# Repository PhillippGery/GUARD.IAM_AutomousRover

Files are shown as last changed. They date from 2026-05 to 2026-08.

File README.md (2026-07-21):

# GUARD.IAM

<p align="center">
  
  
  
  
  
  
  
</p>

<p align="center">
  <b>🥈 2nd Place — Microsoft Track &nbsp;·&nbsp; 🥉 3rd Place — AMD Track</b><br>
  <i>StarkHacks 2026 · World's Largest Hardware Hackathon · 750+ participants · 36 hours</i>
</p>

**G**round **U**nit for **A**utonomous **R**econnaissance, **D**istal **I**ntervention, and **A**rm **M**anipulation — a fully autonomous confined space intervention rover with dual robotic arms, built from scratch in 36 hours at StarkHacks 2026. GUARD.IAM navigates autonomously to a target, executes bimanual manipulation tasks, and hands off to a human operator via **Meta Quest 3 Mixed Reality** when a decision is too critical to automate.

---

## Table of Contents

- [Demo](#demo)
- [Overview](#overview)
- [System Architecture](#system-architecture)
- [Subsystems](#subsystems)
  - [Autonomous Navigation](#autonomous-navigation)
  - [Mecanum Drive & Motor Control](#mecanum-drive--motor-control)
  - [Sensor Fusion & Localization](#sensor-fusion--localization)
  - [Dual-Arm Manipulation](#dual-arm-manipulation)
  - [Mixed Reality Teleoperation](#mixed-reality-teleoperation)
  - [LeRobot Imitation Learning](#lerobot-imitation-learning)
- [Key Algorithms](#key-algorithms)
- [Project Structure](#project-structure)
- [Installation & Build](#installation--build)
- [Running the System](#running-the-system)
- [Configuration Reference](#configuration-reference)
- [ROS2 Topic Reference](#ros2-topic-reference)
- [Dependencies](#dependencies)
- [Team](#team)

---

## Demo

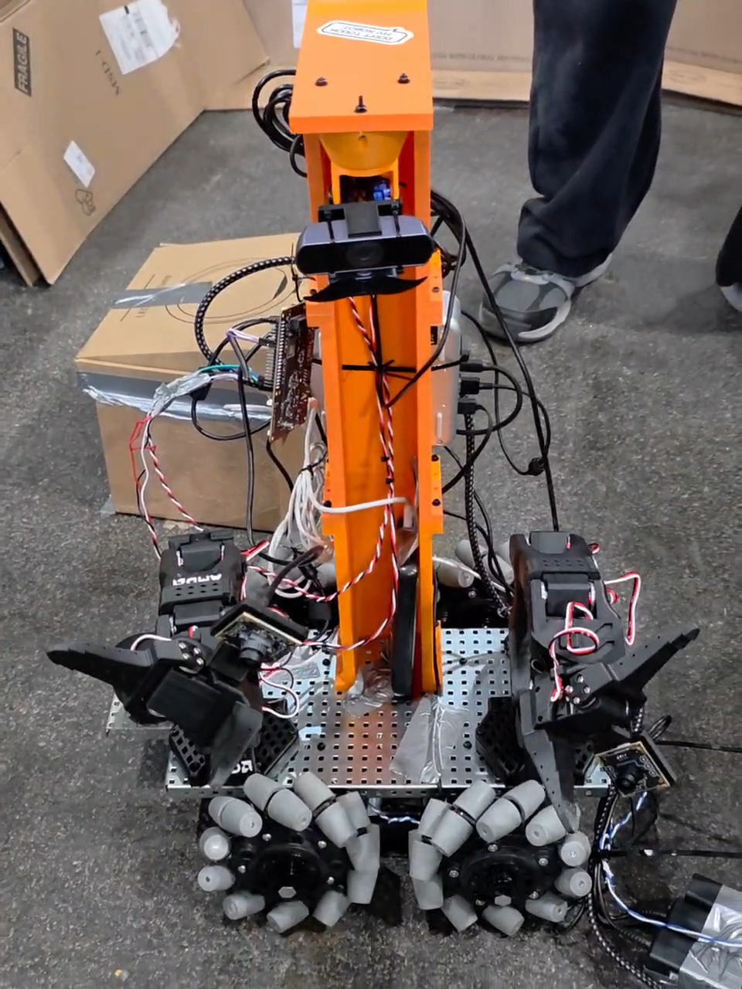
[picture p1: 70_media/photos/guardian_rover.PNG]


*GUARD.IAM v1 — holonomic mecanum platform with dual SO-101 arms, Scanse Sweep LIDAR, Intel RealSense T265, and AMD Ryzen AI compute. Built in 36 hours at StarkHacks 2026.*

Bimanual manipulation demo

*Bimanual manipulation task — dual SO-101 arms executing a coordinated open-box sequence via LeRobot imitation learning.*

---

## Overview

GUARD.IAM is designed for **confined space intervention** — environments where a human cannot safely operate: oil & gas pipelines, nuclear facilities, underground infrastructure. The system combines:

| Layer | Capability |
|---|---|
| **Autonomous navigation** | Nav2 + EKF sensor fusion — navigates to a target without human input |
| **Holonomic drive** | Mecanum kinematics — full omnidirectional movement in tight spaces |
| **Dual-arm manipulation** | SO-101 arms controlled via LeRobot imitation learning |
| **MR teleoperation** | Meta Quest 3 — head-tracked camera, hand-tracking arm control for human-in-the-loop fallback |
| **AI inference** | AMD Ryzen AI MiniPC running VLA policy inference on-board |

**Background:** Three ACS students entered StarkHacks 2026 with no hardware, no chassis, and no working code. 36 hours later they won two prizes and attracted sponsorship interest from AMD, Microsoft, Espressif, Qualcomm, Ouster, and CubeMars. GUARD.IAM is now being developed as a formal ICON Student Team Project at Purdue under Prof. Yu She (MARS Lab) and Prof. Shaoshuai Mou, targeting ICRA/IROS 2027.

---

## System Architecture

```
┌──────────────────────────────────────────────────────────────────────┐
│                         GUARD.IAM Platform                           │
│                                                                      │
│  ┌──────────────────────┐        ┌──────────────────────────────┐   │
│  │  Operator Interface  │        │      Sensor Stack            │   │
│  │                      │        │                              │   │
│  │  Meta Quest 3        │        │  Intel RealSense T265        │   │
│  │  Head-tracked MR     │        │  Scanse Sweep V1 LIDAR       │   │
│  │  Hand tracking       │        │  MPU-6050 IMU                │   │
│  │  SO-101 leader arms  │        │  Wheel encoders              │   │
│  └──────────┬───────────┘        └──────────────┬───────────────┘   │
│             │ WebSocket                          │ ROS2 topics       │
│             ▼                                    ▼                   │
│  ┌──────────────────────────────────────────────────────────────┐   │
│  │                  AMD Ryzen AI MiniPC                          │   │
│  │                     ROS2 Jazzy                                │   │
│  │                                                               │   │
│  │  guardian_bringup     guardian_localization                   │   │
│  │  guardian_drive       guardian_arms                           │   │
│  │  guardian_teleop      guardian_description                    │   │
│  │                                                               │   │
│  │  Nav2 ─── EKF (robot_localization) ─── LeRobot inference     │   │
│  │  Mecanum kinematics ─── /cmd_vel ─── /wheel_rpm              │   │
│  └──────────────────────────┬─────────────────────────────────┘    │
│                              │ USB Serial                            │
│              ┌───────────────┴───────────────┐                      │
│              │     ESP32 Feather V2 ×2        │                      │
│              │  PID ×4 · encoder feedback     │                      │
│              └───┬───────┬───────┬───────┬───┘                      │
│                  ▼       ▼       ▼       ▼                           │
│                 FL      FR      BL      BR                           │
│           [JGB37-3530 encoder motors × 4]                            │
│           [Mecanum wheels × 4]                                       │
└──────────────────────────────────────────────────────────────────────┘
```

---

## Subsystems

### Autonomous Navigation

**Package:** `30_ros2_ws/src/guardian_bringup/`

Nav2 full navigation stack configured for indoor confined spaces. The rover receives a goal pose and autonomously plans and executes a path using the Nav2 behavior tree, replanning dynamically around obstacles detected by the Scanse Sweep LIDAR.

<details>
<summary><b>Launch configurations</b></summary>

One unified launch file, `guardian.launch.py`, covers every combination via arguments:

```bash
ros2 launch guardian_bringup guardian.launch.py                                  # sim, navigation, RViz
ros2 launch guardian_bringup guardian.launch.py use_sim:=false mode:=mapping     # real hardware, SLAM mapping
ros2 launch guardian_bringup guardian.launch.py use_sim:=false                  # real hardware, navigation
ros2 launch guardian_bringup guardian.launch.py rviz:=false                     # headless
```

Key arguments: `use_sim` (`true`/`false`), `mode` (`mapping`/`navigation`), `rviz`,
`teleop`, `map`, `known_pose`, `world`/`spawn_x`/`spawn_y`/`spawn_z` (sim only).
See `30_ros2_ws/src/guardian_bringup/README.md` for the full list.

Nav2 behavior tree: `config/navigate_to_pose.xml` — standard navigate-to-pose with obstacle recovery.

</details>

---

### Mecanum Drive & Motor Control

**Packages:** `30_ros2_ws/src/guardian_drive/` · `20_hardware/arduino/`

Two-layer drive architecture: ROS 2 handles kinematics, ESP32 handles per-wheel PID.

<details>
<summary><b>Mecanum kinematics</b></summary>

`mecanum_kinematics_node.py` converts `/cmd_vel` (`Twist`) to four individual wheel RPM targets:

```
FL = (vx − vy − (L+W)·ω) / r · (60/2π)
FR = (vx + vy + (L+W)·ω) / r · (60/2π)
BL = (vx + vy − (L+W)·ω) / r · (60/2π)
BR = (vx − vy + (L+W)·ω) / r · (60/2π)
```

Peak RPM is clamped while preserving inter-wheel ratios to prevent kinematic distortion at velocity limits.

**Parameters:** `wheel_radius` = 0.0748 m · `wheel_base_length` = 0.25 m · `wheel_base_width` = 0.20 m · `max_rpm` = 251.0

</details>

**ESP32 firmware** (`20_hardware/arduino/guardian_motor_control/`): split front/rear — `ESP32_FRONT` and `ESP32_REAR` each run PID loops for two wheels, reading encoder ticks and outputting PWM. `serial_bridge_node.py` forwards `/wheel_rpm` to the ESP32 over USB serial.

---

### Sensor Fusion & Localization

**Package:** `30_ros2_ws/src/guardian_localization/`

All sensors are fused by `robot_localization` EKF at **50 Hz**, producing `/odometry/filtered` for Nav2. GPS is explicitly excluded — GUARD.IAM operates indoors where GPS is unavailable.

| Sensor | Topic | Rate | Role in EKF |
|---|---|---|---|
| Intel RealSense T265 | `/camera/odom/sample` | 30 Hz | Primary pose — visual-inertial odometry, handles long-term drift |
| Wheel encoders (ESP32) | `/odom` | 50 Hz | Short-term dead reckoning between visual frames |
| MPU-6050 IMU | `/imu/data` | 100 Hz | Orientation, slip/tilt detection |
| Scanse Sweep V1 LIDAR | `/scan` | 5 Hz | Obstacle avoidance, optional scan-matching |

`lidar_republisher_node.py` pre-processes the Scanse Sweep output into a standard `LaserScan` compatible with Nav2's costmap.

---

### Dual-Arm Manipulation

**Package:** `30_ros2_ws/src/guardian_arms/`

Two SO-101 follower arms (LeRobot hardware) mounted on the rover chassis. `arm_manager_node.py` handles joint state publishing and command routing. `teleop_bridge_node.py` relays joint commands from either the Quest 3 hand-tracking interface or the LeRobot policy inference output.

**Training data collection:** `scripts/collect_training_data.py` records synchronized arm joint states + camera frames into the LeRobot dataset format for imitation learning.

**Dataset:** `40_lerobot/datasets/open_box/` — 4 demonstration episodes of a bimanual box-opening task (3 camera streams: `left_camera1`, `left_camera2`, `right_camera3`).

---

### Mixed Reality Teleoperation

**Package:** `30_ros2_ws/src/guardian_teleop/` · `50_teleop/quest_bridge/`

`quest_bridge_node.py` connects to the Meta Quest 3 via WebSocket (`websocket_bridge.py`). Head orientation drives a PTZ camera on the rover. Hand-tracking data is mapped to joint commands for both SO-101 arms via `teleop_bridge_node.py`.

Fallback modes: `joystick_fallback_node.py` (gamepad) and `keyboard_teleop_node.py` (keyboard).

---

### LeRobot Imitation Learning

**Directory:** `40_lerobot/`

SO-101 arm policies trained using [LeRobot](https://github.com/huggingface/lerobot) imitation learning on demonstration episodes.

**Record episodes:**
```bash
bash 40_lerobot/datasets/record_single_arm.sh
bash 40_lerobot/datasets/record_dual_arm.sh
```

**Train:**
```bash
bash 40_lerobot/training/train_single_arm.sh
bash 40_lerobot/training/train_dual_arm.sh
```

**Evaluate:**
```bash
bash 40_lerobot/eval/eval_dual_arm.sh
```

Policy config: `40_lerobot/configs/guardian_policy_config.yaml`

---

## Key Algorithms

### Mecanum Inverse Kinematics

Converts a desired body velocity `(vx, vy, ω)` to four wheel angular velocities. The key property of mecanum drive is that the 45° roller angle on each wheel projects lateral force components — allowing full holonomic motion (translation in any direction + rotation simultaneously) without wheel steering.

```
[FL]   [ 1  -1  -(L+W)] [vx]
[FR] = [ 1   1   (L+W)] [vy] · (1/r) · (60/2π)
[BL]   [ 1   1  -(L+W)] [ω ]
[BR]   [ 1  -1   (L+W)]
```

### EKF Sensor Fusion

`robot_localization` fuses three asynchronous sources at 50 Hz. The T265 provides absolute pose correction to prevent VIO drift; wheel odometry provides high-rate dead reckoning between visual frames; the IMU provides orientation priors that stabilize the EKF on slopes and during acceleration transients.

### PID Wheel Control (ESP32)

Each of the four wheels runs an independent PID loop on the ESP32. Encoder tick counts are compared against the RPM target from the ROS 2 kinematics node, and PWM duty cycle is adjusted to minimize the error. Front and rear ESP32 boards are split to reduce serial latency — each handles exactly two wheels.

---

## Project Structure

```
AutomousRover_StarkHacks/
├── README.md
├── figures/
│   ├── guardian_rover.jpg                ← rover photo
│   └── bimanual_manipulation_demo.mp4    ← bimanual task demo
├── 10_docs/                              ← architecture, hardware, setup docs
│   ├── architecture/
│   │   ├── system_overview.md
│   │   ├── control_architecture.md
│   │   └── sensor_fusion.md
│   ├── hardware/
│   │   ├── bill_of_materials.md
│   │   ├── wiring_diagram.md
│   │   └── power_system.md
│   └── setup/
│       ├── dependencies.md
│       ├── amd_minipc_setup.md
│       └── arduino_setup.md
├── 20_hardware/                          ← CAD and embedded firmware
│   ├── arduino/guardian_motor_control/
│   │   ├── ESP32_FRONT/                  ← front-left + front-right PID
│   │   ├── ESP32_REAR/                   ← rear-left + rear-right PID
│   │   └── ESP_Final/                    ← production firmware
│   └── cad/                              ← chassis CAD files
├── 30_ros2_ws/                           ← ROS 2 Jazzy colcon workspace
│   └── src/
│       ├── guardian_bringup/             ← launch files + Nav2 config
│       ├── guardian_description/         ← URDF/xacro robot model
│       ├── guardian_drive/               ← mecanum kinematics + serial bridge
│       │   └── guardian_drive/
│       │       ├── mecanum_kinematics_node.py
│       │       └── serial_bridge_node.py
│       ├── guardian_localization/        ← LIDAR republisher, EKF prep
│       ├── guardian_arms/                ← dual SO-101 arm control + LeRobot bridge
│       └── guardian_teleop/              ← Quest 3 + joystick + keyboard teleop
├── 40_lerobot/                           ← imitation learning pipeline
│   ├── datasets/
│   │   ├── open_box/                     ← 4-episode bimanual box dataset
│   │   ├── record_single_arm.sh
│   │   └── record_dual_arm.sh
│   ├── training/
│   │   ├── train_single_arm.sh
│   │   └── train_dual_arm.sh
│   ├── eval/
│   └── configs/guardian_policy_config.yaml
├── 50_teleop/                            ← Meta Quest 3 WebSocket bridge
│   └── quest_bridge/
│       └── websocket_bridge.py
└── 60_scripts/                           ← convenience scripts
    ├── run_guardian.sh                   ← one-command full system launch
    ├── build_workspace.sh
    └── setup_amd_minipc.sh
```

---

## Installation & Build

### Prerequisites

- **Ubuntu 24.04** + **ROS 2 Jazzy**
- **Nav2**: `ros-jazzy-navigation2 ros-jazzy-nav2-bringup`
- **robot_localization**: `ros-jazzy-robot-localization`
- **RealSense**: `ros-jazzy-realsense2-camera`
- **LeRobot** (Python): `pip install lerobot`
- **PlatformIO** (for ESP32 firmware)

```bash
sudo apt install \
  ros-jazzy-navigation2 ros-jazzy-nav2-bringup \
  ros-jazzy-robot-localization \
  ros-jazzy-realsense2-camera \
  ros-jazzy-teleop-twist-keyboard
```

### Build

```bash
git clone --recurse-submodules https://github.com/PhillippGery/AutomousRover_StarkHacks.git
cd AutomousRover_StarkHacks
# Already cloned without --recurse-submodules? Run:
#   git submodule update --init --recursive

# Install ROS dependencies
cd 30_ros2_ws
rosdep install --from-paths src --ignore-src -r -y

# Build
colcon build --symlink-install
source install/setup.bash
```

### Flash ESP32 Firmware

```bash
# Front wheels (FL + FR)
cd 20_hardware/arduino/guardian_motor_control/ESP32_FRONT
pio run --target upload

# Rear wheels (BL + BR)
cd ../ESP32_REAR
pio run --target upload
```

---

## Running the System

One unified launch file, `guardian.launch.py`, covers every mode via arguments —
sim vs. real hardware, mapping vs. navigation, RViz on/off, teleop on/off.

### Sim, autonomous navigation (default)

```bash
cd 30_ros2_ws && source install/setup.bash
ros2 launch guardian_bringup guardian.launch.py
```

Or via convenience script (interactive menu):
```bash
bash 60_scripts/run_guardian.sh
```

### Mapping (build a map first — real hardware; mapping a sim world isn't useful)

```bash
ros2 launch guardian_bringup guardian.launch.py use_sim:=false mode:=mapping
```

### Real hardware, navigation

```bash
ros2 launch guardian_bringup guardian.launch.py use_sim:=false
```

### Teleoperation only

```bash
ros2 run guardian_teleop keyboard_teleop_node
```

### Meta Quest 3 bridge

```bash
python3 50_teleop/quest_bridge/websocket_bridge.py
```

---

## Configuration Reference

| Parameter | Default | Description |
|---|---|---|
| `wheel_radius` | 0.0775 m | Mecanum wheel radius (6" VEXpro), CAD-measured |
| `wheel_base_length` | 0.313588 m | Front-to-rear wheel center distance, CAD-measured |
| `wheel_base_width` | 0.390755 m | Left-to-right wheel center distance, CAD-measured |
| `max_rpm` | 170.0 | Maximum wheel RPM (DCM4109 rated max, clamped with ratio preservation) |
| EKF rate | 50 Hz | `robot_localization` filter update rate |
| T265 rate | 30 Hz | Visual-inertial odometry input rate |
| IMU rate | 100 Hz | MPU-6050 orientation input rate |
| LIDAR rate | 5 Hz | Scanse Sweep scan rate |

Config files: `30_ros2_ws/src/guardian_bringup/config/`

---

## ROS2 Topic Reference

| Topic | Type | Publisher | Subscriber |
|---|---|---|---|
| `/cmd_vel` | `Twist` | Nav2 / teleop nodes | mecanum_kinematics_node |
| `/wheel_rpm` | `Float32MultiArray` | mecanum_kinematics_node | serial_bridge_node |
| `/odom` | `Odometry` | serial_bridge_node (ESP32) | EKF |
| `/camera/odom/sample` | `Odometry` | RealSense T265 | EKF |
| `/imu/data` | `Imu` | ESP32 (MPU-6050) | EKF |
| `/odometry/filtered` | `Odometry` | robot_localization EKF | Nav2 |
| `/scan` | `LaserScan` | lidar_republisher_node | Nav2 costmap |
| `/joint_states` | `JointState` | arm_manager_node | LeRobot / teleop |
| `/arm/joint_commands` | `JointTrajectoryPoint` | teleop_bridge / LeRobot | arm_manager_node |

---

## Dependencies

### ROS 2 Packages
`rclpy` · `rclcpp` · `nav2` · `robot_localization` · `realsense2_camera` · `sensor_msgs` · `geometry_msgs` · `nav_msgs` · `trajectory_msgs`

### Python
`lerobot` · `numpy` · `websockets` · `pyserial`

### Embedded
**PlatformIO** · ESP32 Feather V2 · `PID_v1` library

### Hardware
**AMD Ryzen AI MiniPC** · **SO-101 robotic arms ×2** · **Intel RealSense T265** · **Scanse Sweep V1 LIDAR** · **JGB37-3530 encoder motors ×4** · **VEXpro 6" mecanum wheels ×4** · **Meta Quest 3**

---

## Team

| Member | Role |
|---|---|
| **Phillipp Gery** (Lead) | ROS2 architecture, Nav2, EKF, mecanum kinematics — MS ACS, Purdue, Fulbright Scholar |
| **Vedant Patkar** | Arduino low-level control, PID, encoder odometry — MS ACS, Purdue |
| **Victor Hu** | Chassis CAD/build, power system, Quest MR interface — MS ACS, Purdue |

**Faculty Advisors:** Prof. Yu She (Director, MARS Lab, ICON) · Prof. Shaoshuai Mou (Co-Director, ICON), Purdue University

---

*StarkHacks 2026 · Purdue University · ICON Lab · MARS Lab*

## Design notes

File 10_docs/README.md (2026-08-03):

# GUARDIAN Documentation

This folder is the single source of truth for all GUARDIAN project documentation.

## Subfolders

| Folder | Contents |
|---|---|
| [architecture/](architecture/) | System overview, control architecture, sensor fusion design |
| [hardware/](hardware/) | Bill of materials, wiring diagrams, power system design |
| [setup/](setup/) | Step-by-step setup guides for AMD MiniPC, Arduino, and dependencies |

## Navigation

- Start with [architecture/system_overview.md](architecture/system_overview.md) for the big picture.
- Refer to [hardware/bill_of_materials.md](hardware/bill_of_materials.md) for component inventory.
- Follow [setup/amd_minipc_setup.md](setup/amd_minipc_setup.md) to bring up the compute platform.
- Follow [setup/web_control_interface_setup.md](setup/web_control_interface_setup.md) to set up the browser (Foxglove) control interface and boot-time hardware auto-start.

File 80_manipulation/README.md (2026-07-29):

# GUARD.IAM — Bimanual Manipulation Pipeline

End-to-end ACT imitation-learning pipeline for the dual-arm GUARD.IAM follower:
teleoperate → collect demonstrations → train an ACT policy → run it on the real arms.

Built on the **equibim** LeRobot fork
(`git@github.com:ZhangZhiyuanZhang/lerobot-equibim.git`). This repo contains only
the pipeline scripts; the fork and ML dependencies are installed separately (below).

> ⚠️ Read the **Gotchas** section before your first real collection run. Several
> settings (FPS, MJPG, normalization) are load-bearing and expensive to get wrong.

---

## 0. Prerequisites

- Linux (developed on Ubuntu 24.04) with an NVIDIA GPU + recent driver.
  Verify: `nvidia-smi` should print the GPU table. If it errors with
  "Driver/library version mismatch", **reboot** first.
- [Miniforge / Miniconda](https://github.com/conda-forge/miniforge) installed.
- GitHub access to the **equibim** repo (SSH key set up, or use HTTPS + token).
- Dual-arm SO-101 hardware: 2 leaders, 2 followers, 3 USB cameras
  (2 wrist + 1 overhead), ideally on a **powered USB hub**.

---

## 1. Environment setup (conda)

```bash
# From this directory (80_manipulation/):
conda env create -f environment.yml
conda activate lerobot
```

> **Always work inside this env.** All dependencies live here. Do NOT
> `conda deactivate` while debugging — `pip install` works inside conda
> (no `--break-system-packages` needed).

If `conda env create` fails on the CUDA/torch pin (GPU/driver differences),
create a bare env and install torch manually:
```bash
conda create -n lerobot python=3.12 -y && conda activate lerobot
# install torch for your CUDA version per https://pytorch.org, then continue to step 2
```

---

## 2. Install the equibim LeRobot fork

The pipeline imports `lerobot` from the **equibim** fork (not stock LeRobot).

```bash
# SSH (needs GitHub SSH access):
git clone git@github.com:ZhangZhiyuanZhang/lerobot-equibim.git lerobot-equibim
# or HTTPS:
# git clone https://github.com/ZhangZhiyuanZhang/lerobot-equibim.git lerobot-equibim

cd lerobot-equibim
pip install -e .
cd ..
```

Verify it imports from the fork:
```bash
python -c "import lerobot; print(lerobot.__file__)"   # should point into lerobot-equibim/
```

---

## 3. Install remaining Python deps

```bash
pip install -r requirements.txt
```
(Includes `evdev` for the foot pedal. `requirements.txt` also re-pins the equibim
fork; the editable install in §2 takes precedence and is fine.)

---

## 4. Per-machine hardware setup (REQUIRED — does not transfer from git)

### 4a. udev symlinks (stable device names)

```bash
sudo cp ../60_scripts/99-guardian.rules /etc/udev/rules.d/
sudo udevadm control --reload-rules && sudo udevadm trigger
```

Expected (verify with `ls -l /dev/cam_* /dev/guardian_*`):
- `/dev/cam_left_wrist`, `/dev/cam_right_wrist`, `/dev/cam_overhead`
- `/dev/guardian_left_follower`, `/dev/guardian_right_follower`
- `/dev/guardian_left_leader`, `/dev/guardian_right_leader`

Arm-count sanity check (must print 4):
```bash
ls /dev/guardian_* | wc -l
```

> If you re-plug USB or change the hub, the underlying `3-x.y` port paths change
> and the symlinks break. Re-derive with:
> ```bash
> for d in /dev/ttyACM* /dev/video*; do
>   printf '%-16s %s\n' "$d" "$(udevadm info -a -n "$d" 2>/dev/null | grep -m1 KERNELS)"
> done
> ```
> then update the `KERNELS==` values in `99-guardian.rules` and reload.

### 4b. Camera format check (must support MJPG)

```bash
v4l2-ctl -d /dev/cam_left_wrist  --list-formats-ext   # confirm MJPG @ 640x480
v4l2-ctl -d /dev/cam_right_wrist --list-formats-ext
v4l2-ctl -d /dev/cam_overhead    --list-formats-ext
```
All three must offer MJPG at 640×480 (see Gotchas for why).

### 4c. Calibration

Each follower needs a calibration file in the LeRobot calibration cache:
`~/.cache/huggingface/lerobot/calibration/robots/bi_so_follower/`
- `left_guardian_follower.json`
- `right_guardian_follower.json`

> **The robot ids in `config.py` MUST match these filenames**
> (`left_guardian_follower`, `right_guardian_follower`, and the bimanual id
> `guardian_follower`). If they don't match, the arms prompt to recalibrate on
> connect — do NOT recalibrate over a working setup; fix the ids instead.

### 4d. Edit `config.py`

At the top of `config.py`, set:
- `PORT_*` — udev symlink paths for each arm
- `ID_*` — must match the calibration filenames (§4c)
- camera symlink paths, resolution, and **FPS = 20**

`config.py` is the single source of truth shared by collect, train, and inference.
Anything set here (cameras, fps, rotation) applies everywhere.

---

## 5. Foot pedal (optional — hands-free collection)

X-keys XK-3 foot pedal → arrow keys. Bridge: `../60_scripts/pedal_bridge.py`.

```bash
pip install evdev   # (already in requirements.txt)

# Run in a SECOND terminal, alongside collect.py. Needs sudo to read the device:
sudo $(which python) ../60_scripts/pedal_bridge.py
```

Mapping: **LEFT pedal → LEFT arrow** (scrap & redo), **RIGHT pedal → RIGHT arrow**
(keep & continue), **CENTER unmapped**. ESC (stop) stays on the keyboard.

Troubleshooting: if the pedal isn't found, run `sudo evtest`, find the XK-3 node
exposing `BTN_*` events, and set that `/dev/input/eventNN` path in
`pedal_bridge.py`. (Event numbers can shift across reboots.)

---

## 6. Teleoperation (verify arms + cameras)

```bash
python teleop_test.py
```
Drives followers from the leaders; streams the 3 camera feeds + state to rerun.
**Check:** each follower gripper fully opens AND closes, and all three feeds are
clean (no tearing). Fix any issue here before collecting.

---

## 7. Data collection

```bash
python collect.py
```

**Controls (foot pedal or keyboard):**

| Action | Key | Pedal |
|---|---|---|
| Keep episode, continue | RIGHT arrow | Right pedal |
| Scrap & re-record | LEFT arrow | Left pedal |
| Stop session | ESC | (keyboard only) |

**Before a REAL run:**
- Set `WIPE_BEFORE_RUN = False` (practice mode wipes the dataset each run).
- Use a real, unique `REPO_ID` (keep practice on a separate id like `guardian_practice`).
- **Reseat the left follower** — it can drop off the bus mid-episode and silently
  corrupt a take.
- Use a generous `EPISODE_TIME_SEC` (e.g. 60); RIGHT ends early when you finish,
  so long timers cost nothing.

**Collect good demos:** complete the task fully every episode (object placed,
grippers released), vary object position across episodes, scrap any fumble.

**Verify after collecting** (dataset loads + all 12 joints move):
```bash
python - <<'PY'
from lerobot.datasets.lerobot_dataset import LeRobotDataset
import numpy as np
d = LeRobotDataset("vedant/guardian_pick_place")   # <-- your REPO_ID
print("episodes", d.num_episodes, "frames", d.num_frames, "fps", d.fps)
s = np.stack([d[i]["observation.state"].numpy() for i in range(0, len(d), 50)])
print("per-joint range (all should be clearly > 0):", np.round(s.max(0)-s.min(0), 2))
PY
```

---

## 8. Training

```bash
python train.py
```
Wraps the fork's `lerobot-train` for ACT. Config block at the top:
- `STEPS` — 40k–100k for a real run. Watch the loss plateau; steps past it buy
  little. **Judge the policy by evaluating checkpoints on the arms, not loss alone.**
- `SAVE_FREQ = 10000` — checkpoints in `outputs/train/<job>/checkpoints/NNNNNN/`.
- `USE_WANDB` — optional. If used, run `wandb login` once. Loss also prints to console.

Leave the machine on AC power for long runs; it checkpoints every `SAVE_FREQ`
steps whether or not you're watching.

---

## 9. Inference (run the policy on the arms)

```bash
python bimanual_inference.py
```
Loads a checkpoint and drives the followers through the fork's `record_loop`.

Set at the top of `bimanual_inference.py`:
- `LOCAL_CKPT_PATH` — a checkpoint's `pretrained_model` dir, e.g.
  `outputs/train/guardian_act/checkpoints/060000/pretrained_model`
- `FPS = 20` (must match training)
- `USE_HOME_RESET` — `True` only if you have a `home_action.json` home pose

**Before running:** reseat the left follower; keep a hand near Ctrl-C on the first
rollout (a fresh policy can move abruptly).

**Sanity-check a checkpoint without the robot** — predicted actions should match
the demonstrated actions on training frames (within a few degrees per joint):
```bash
python - <<'PY'
from lerobot.datasets.lerobot_dataset import LeRobotDataset
from lerobot.policies.act.modeling_act import ACTPolicy
from lerobot.processor import PolicyProcessorPipeline
import torch, numpy as np
ck = "outputs/train/guardian_act/checkpoints/100000/pretrained_model"  # <-- your checkpoint
ds = LeRobotDataset("vedant/guardian_pick_place")                       # <-- your REPO_ID
p = ACTPolicy.from_pretrained(ck); p.config.device="cuda"; p.to("cuda").eval(); p.reset()
pre  = PolicyProcessorPipeline.from_pretrained(ck, "policy_preprocessor.json")
post = PolicyProcessorPipeline.from_pretrained(ck, "policy_postprocessor.json")
for i in range(5):
    f = ds[i]; obs = {k: f[k] for k in f if k.startswith("observation")}; obs["task"]=f["task"]
    a = post({"action": p.select_action(pre(obs))})
    a = a["action"] if isinstance(a, dict) and "action" in a else a
    a = a.squeeze(0).detach().cpu().numpy() if torch.is_tensor(a) else np.asarray(a).squeeze()
    print("pred", np.round(a,1)); print("true", f["action"].numpy().round(1))
PY
```
If `pred` tracks `true`, inference is correct and any remaining gap is data quality.

---

## Gotchas (hard-won — DO NOT IGNORE)

- **FPS = 20 everywhere.** Collect, train, AND infer must all use 20 fps. 30 fps
  overruns the shared USB2 hub and starves a camera (torn frames / timeouts).
  Whatever fps you collect at is locked for training and inference.
- **3 cameras require `fourcc="MJPG"`** at 640×480. Raw YUYV exceeds the hub's
  bandwidth and causes tearing / camera timeouts. (Powered hub and longer read
  timeouts did NOT fix it — dropping to 20 fps + MJPG did.)
- **Overhead camera is mounted upside down** → `rotation=ROTATE_180` in `config.py`.
  Baked into the data; keep it identical between collect and infer.
- **`collect.py` must finalize the dataset before exit**, or `meta/episodes` never
  gets written and the dataset won't load. This repo's `collect.py` calls the
  finalize step explicitly before disconnect/exit (a bare `os._exit(0)` is NOT
  enough — it skips finalization).
- **Inference normalization comes from the checkpoint's SAVED processors.** Use the
  fork's `record_loop` + `make_pre_post_processors(pretrained_path=...)` (as
  `bimanual_inference.py` does). Recomputing normalization from dataset stats gives
  WRONG numbers and the policy collapses to a fixed pose.
- **Robot ids must match calibration filenames** (§4c) or the arms re-prompt to
  calibrate.
- **The left follower is the flaky one** — reseat its USB + power before real runs;
  a mid-episode bus drop silently corrupts data and fakes inference "failures".
- **Resolution / fps / camera set at collection must exactly match inference.**

---

## Not included in this repo (by design)

- **Datasets** (`~/.cache/huggingface/lerobot/...`) — too large. Re-collect, or
  pull a shared dataset from the HuggingFace Hub.
- **Checkpoints** (`outputs/train/...`) — too large. Share trained policies via the
  HuggingFace Hub and load with `from_pretrained("<hub_id>")`.
- **The equibim fork** — installed as a dependency (§2), not vendored here.

---

## Repo layout (relevant paths)

```
80_manipulation/
  config.py                 # single source of truth: ports, ids, cameras, fps
  teleop_test.py            # verify arms + cameras
  collect.py                # record demonstrations
  train.py                  # train ACT (wraps lerobot-train)
  bimanual_inference.py     # run a policy on the arms
  environment.yml           # conda env (this pipeline's deps)
  requirements.txt          # pip extras (evdev, equibim pin)
  README.md                 # this file
../60_scripts/
  99-guardian.rules         # udev rules for camera/arm symlinks
  pedal_bridge.py           # X-keys foot pedal → arrow keys
  aim_overhead.py           # overhead PTZ aim tool
```

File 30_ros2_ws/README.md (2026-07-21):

# GUARDIAN ROS2 Workspace

ROS2 Jazzy workspace — Ubuntu 24.04, pure Python (ament_python).

## Packages

| Package | Owner | Purpose |
|---|---|---|
| [guardian_bringup](src/guardian_bringup/) | Phillipp | Launch files, EKF/Nav2/RViz config — no nodes of its own |
| [guardian_description](src/guardian_description/) | Phillipp | URDF/xacro robot model (CAD-derived meshes) + Gazebo sim world |
| [guardian_drive](src/guardian_drive/) | Phillipp/Vedant | Mecanum kinematics + Phidgets DCC1120 motor bridge (`phidget_bridge_node`, direct VINT/Phidget22 API — `serial_bridge_node` is an older serial-port-based fallback) |
| [guardian_localization](src/guardian_localization/) | Phillipp | LIDAR republisher (self-occlusion masking) + front/back scan merger, feeds Nav2 |
| [guardian_manipulation](src/guardian_manipulation/) | Dipam | Dual SO-101 arm management + LeRobot bridge |
| [guardian_navigation](src/guardian_navigation/) | Phillipp | Automatic AMCL localization bootstrap on launch |
| [guardian_teleop](src/guardian_teleop/) | Victor | Quest 3 + joystick + keyboard (evdev, real press/release) teleoperation |

---

## Build

```bash
cd ~/AutomousRover_StarkHacks/30_ros2_ws
source /opt/ros/jazzy/setup.bash
colcon build
source install/setup.bash
```

Build a single package:
```bash
colcon build --packages-select <package_name>
```

---

## Keyboard Teleop (WASD)

Reads the keyboard directly via evdev (real press/release, holds a direction
only while the key is down, multiple keys combine for diagonal driving) — see
`guardian_teleop`'s README for one-time `input`-group setup.

```bash
cd ~/GUARD.IAM_AutomousRover/30_ros2_ws
source /opt/ros/jazzy/setup.bash && source install/setup.bash
ros2 run guardian_teleop keyboard_teleop_node
```

Controls:
| Key | Action |
|-----|---|
| `w` | Forward |
| `s` | Backward |
| `a` | Strafe left |
| `d` | Strafe right |
| `q` | Rotate left |
| `e` | Rotate right |
| `space` / `k` | Stop |
| `+` / `-` | Speed up/down |
| `x` / `Esc` | Quit |

---

## LIDAR

> Two Scanse Sweep units (front + back), each on a stable udev-assigned path —
> see `60_scripts/README.md` for the one-time `/dev/lidar_front`/`/dev/lidar_back`
> setup (do not hardcode `/dev/ttyUSB0`/`1`, which shift with USB plug order).

Brought up automatically by `guardian.launch.py` (both units → merged, masked
`/scan_filtered`). To check a single raw unit directly:

```bash
source /opt/ros/jazzy/setup.bash && source install/setup.bash
ros2 topic echo /scan --once        # front, raw
ros2 topic echo /scan_back --once   # back, raw
ros2 topic echo /scan_filtered --once  # merged + masked, what Nav2/SLAM use
```

---

## Check Connected Hardware

```bash
# All USB devices
lsusb

# Serial ports (LIDARs — see udev setup above for stable /dev/lidar_front/back)
ls /dev/ttyUSB* /dev/ttyACM*

# Camera
ls /dev/video*
```

---

## Hardware Setup

### Drive Motors — Phidgets DCC1120 / DCM4109

Four Phidgets DCC1120 BLDC motor controllers on one VINT hub, addressed by hub
port (all four controllers report the hub's own serial number, not their own —
see `phidget_bridge_node.py`'s header comment for the full addressing model).
`20_hardware/phidgets/enumerate_phidgets.py` maps hub ports to controllers;
`20_hardware/phidgets/spin_test.py` bench-tests individual wheels.

| Parameter | Value |
|---|---|
| Motor | DCM4109, NEMA23 BLDC, 22.667:1 gearbox |
| Rated max speed | 170 RPM (wheel output) |
| Encoder | Built-in hall sensors — 4-pole x 6 states/electrical-rev x gearbox = 272 ticks/wheel-rev (confirmed on the real robot) |
| Wheel | VEX Pro 6" mecanum, radius 0.0775 m (CAD-measured) |

All of the above live in one place — `guardian_bringup/config/robot_params.yaml`'s
`/**` wildcard block — not scattered per-node.

### Lidar Reset (if node crashes on startup)

The Scanse Sweep segfaults if left in data-streaming mode. Reset before launching
(replace the port with whichever raw `/dev/ttyUSBn` that unit is currently on):

```bash
stty -F /dev/ttyUSB0 115200 && printf 'DX\n' > /dev/ttyUSB0 && sleep 1 && printf 'RR\n' > /dev/ttyUSB0 && sleep 3
```

---

## Launch Files

One unified launch file covers every combination — see
`30_ros2_ws/src/guardian_bringup/README.md` for the full argument list.

| Launch | Purpose | Hardware needed |
|---|---|---|
| `guardian.launch.py mode:=mapping` | Drive + LIDAR + SLAM mapping | Motors + Sweep (or none, in sim) |
| `guardian.launch.py` (default) | Full Nav2 stack, autonomous navigation | Motors + Sweep (or none, in sim) |
| `guardian.launch.py use_sim:=false` | Real hardware instead of Gazebo | Motors + Sweep |

`ros2 run guardian_teleop keyboard_teleop_node` drives with keyboard only, standalone.

---

## Mapping (Real Robot)

> Requires the Phidgets DCC1120 motor controllers (see `guardian_drive`) and the
> Scanse Sweep LIDAR(s) on their udev-assigned `/dev/lidar_front`/`/dev/lidar_back`
> ports (see `60_scripts/README.md` for one-time setup).

```bash
source /opt/ros/jazzy/setup.bash && source install/setup.bash
ros2 launch guardian_bringup guardian.launch.py use_sim:=false mode:=mapping
```

Drive around with the keyboard (teleop auto-enables in mapping mode). Map builds
in RViz automatically. SLAM params: `minimum_travel_distance: 0.0` — map updates
even when stationary.

---

## Gazebo Simulation + Autonomous Navigation

> No hardware required — full sim with SLAM, Nav2, and keyboard teleop

```bash
source /opt/ros/jazzy/setup.bash && source install/setup.bash
ros2 launch guardian_bringup guardian.launch.py
```

### What launches
- Gazebo Harmonic world, robot spawns after ~3s
- Front + back GPU lidars merged into `/scan_filtered`; `/odom` + `/tf` from the
  MecanumDrive plugin (holonomic — DiffDrive can't strafe and isn't used)
- SLAM Toolbox (mapping mode) or AMCL + a saved map (navigation mode, default)
- Nav2 lifecycle auto-starts (`autostart: true` — no manual "Startup" click needed)
- RViz opens by default (`rviz:=true`) with the map, costmaps, and global/local path displays
- Teleop keyboard reads the keyboard directly via evdev (real press/release,
  multi-key diagonal driving) — auto-enabled in mapping mode

### Build the map first
Drive around with the keyboard to build the SLAM map before sending Nav2 goals
(`mode:=mapping`, then `30_ros2_ws/src/guardian_bringup/scripts/save_map.sh`).

### Send an autonomous navigation goal
1. Click the **Nav2 Goal** tool (green arrow) in the RViz toolbar
2. Click a position on the map and drag to set heading
3. Release — robot drives autonomously, avoiding obstacles

Verify:
```bash
ros2 topic hz /scan    # ~5Hz
ros2 topic hz /odom    # ~50Hz
ros2 topic hz /map     # ~1Hz
ros2 topic echo /plan --once | head -5   # path published when goal set
ros2 topic echo /cmd_vel | head -5       # velocities while navigating
```

### Nav2 config notes
- `autostart: true` — Nav2 lifecycle starts automatically on launch
- `bond_timeout: 0.0` — disables heartbeat bonds (sim clock vs wall clock mismatch)
- `wait_for_service_timeout: 3000` — gives behavior_server 3s to come up before bt_navigator connects
- Behavior plugin named `backup` (no underscore) — matches what default BT XML expects (`/backup` action server)
- `behavior_plugins: ['spin', 'backup', 'drive_on_heading', 'wait', 'assisted_teleop']`

---

## SLAM Toolbox Key Parameters

Configured in `src/guardian_bringup/config/nav2_params.yaml`:

| Parameter | Value | Why |
|---|---|-----|
| `minimum_travel_distance` | 0.0 | Map updates even when stationary |
| `minimum_travel_heading` | 0.0 | Map updates without rotation |
| `map_update_interval` | 1.0 s | Fast map refresh |
| `max_laser_range` | 8.0 m | Matches Scanse Sweep range |

**Important:** The SLAM launch argument must be `slam_params_file` (not `params_file`) — this is the key that `online_async_launch.py` actually reads.

---

## Useful ROS2 Debug Commands

```bash
# List all active topics
ros2 topic list

# Monitor cmd_vel
ros2 topic echo /cmd_vel

# Monitor wheel RPM
ros2 topic echo /wheel_rpm

# Monitor odometry
ros2 topic echo /odom

# List active nodes
ros2 node list
```

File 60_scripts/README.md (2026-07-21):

# Scripts

Convenience shell scripts for setup, building, and running GUARDIAN.

| Script | Purpose |
|---|---|
| `setup_amd_minipc.sh` | One-shot install of all system dependencies on Ubuntu 22.04 |
| `build_workspace.sh` | Source ROS2, install deps, build workspace |
| `run_guardian.sh` | Interactive launch menu |
| `guardiam_env.sh` | Per-session env: sources ROS2 Jazzy + workspace, sets `ROS_DOMAIN_ID=42`, defines `guardiam_sim`/`guardiam_real`/`guardiam_map`/`cb`/`cbs` aliases |
| `identify_lidar_port.sh` | Print a connected USB-serial device's identifying info (serial number, etc.), one LIDAR at a time |
| `99-guardian-lidar.rules` | udev rules template pinning `/dev/lidar_front`/`/dev/lidar_back` to each LIDAR's own USB serial number |

## Usage

```bash
# First-time setup (run once after cloning)
bash 60_scripts/setup_amd_minipc.sh

# Build workspace
bash 60_scripts/build_workspace.sh

# Launch
bash 60_scripts/run_guardian.sh
```

`setup_amd_minipc.sh` adds `source 60_scripts/guardiam_env.sh` to `~/.bashrc` automatically. To pick it up in your current shell without re-running setup:

```bash
source 60_scripts/guardiam_env.sh
```

## One-time: labeling the front/back LIDARs

The real robot has two identical Scanse Sweep LIDAR units, and `guardian.launch.py`'s real-hardware branch expects them at the stable paths `/dev/lidar_front` and `/dev/lidar_back` — not raw `/dev/ttyUSB0`/`1`, which Linux assigns by USB enumeration order and can silently swap between the two physical units on a reboot or replug.

```bash
# 1. Plug in ONE LIDAR (unplug the other / any other USB-serial adapter)
bash 60_scripts/identify_lidar_port.sh
# Read off the ATTRS{serial} value shown. Physically label that unit
# (tape marked "F" for front, or "B" for back) so the label matches
# which end of the chassis it's actually mounted on.

# 2. Unplug it, plug in the second LIDAR, repeat step 1 for its serial.

# 3. Put both serial numbers into 60_scripts/99-guardian-lidar.rules
#    (replacing REPLACE_WITH_FRONT_SERIAL / REPLACE_WITH_BACK_SERIAL),
#    then install it:
sudo cp 60_scripts/99-guardian-lidar.rules /etc/udev/rules.d/
sudo udevadm control --reload-rules
sudo udevadm trigger

# 4. Plug both LIDARs in and confirm:
ls -la /dev/lidar_front /dev/lidar_back
```

Do this once per robot; it survives reboots and USB replugs from then on.

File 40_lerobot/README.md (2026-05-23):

# LeRobot

**Owner: Dipam**

This folder contains LeRobot-specific configs, training datasets, and trained policy checkpoints for GUARDIAN's dual-arm manipulation system.

## Subfolders

| Folder | Contents |
|---|---|
| [configs/](configs/) | Policy configuration YAML files |
| [training/](training/) | Training scripts and logs |
| [datasets/](datasets/) | Recorded demonstration datasets |

## Setup

Follow the official LeRobot documentation: https://github.com/huggingface/lerobot

```bash
cd ~/GUARDIAN/30_ros2_ws/src
git clone https://github.com/huggingface/lerobot
cd lerobot
pip install -e ".[feetech]"
```

## Workflow

1. **Collect demonstrations** — run `guardian_arms/scripts/collect_training_data.py` with leader arms to record episodes
2. **Train policy** — use `40_lerobot/configs/guardian_policy_config.yaml` to configure and train ACT or Diffusion Policy
3. **Deploy** — load checkpoint in `arm_manager_node.py` for autonomous execution

## Hardware

- SO-101 leader arms (for teleoperation and demonstration recording)
- SO-101 follower arms mounted on GUARDIAN chassis

## Setup

- Follow the tutorial on LeRobot to setup the leader and follower arms
- Calibrate both the arms and test teleop mode. Verify both the arms are moving in perfect sync.

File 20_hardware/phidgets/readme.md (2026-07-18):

# Phidget Motor Setup — read this before you plug anything in

Notes to future me, and anyone else spinning up the drivetrain. This is the
rehash running on Phidget controllers instead of the old Arduino/ESP32 rig I
built for the hackathon, so ignore muscle memory from that version. If a motor
won't move, the answer is almost always somewhere in here.

Two scripts live next to this file:
- `attach_test.py` — checks a controller is talking. No motion.
- `spin_test.py` — actually spins one motor.

## What I'm working with

- **DCM4109_1** — the motor. 24V brushless, NEMA23, 23:1 gearbox, hall sensors
  built in. Torquey and slow, tops out around 170 RPM at the output.
- **DCC1120** — the controller. One per motor. Handles the commutation and
  talks to the PC over VINT.
- **VINT Hub** — the USB bridge. All four controllers hang off this, and it
  plugs into the MiniPC over one USB cable.

One controller per motor, four total, all sharing the single hub.

## Step 0 — deps

```
pip install Phidget22
```

On Linux you also need a udev rule, but that's Step 3.

## Step 1 — wiring (leave everything powered OFF here)

Phase wires, motor to controller terminals:

- RED    -> A (U)
- YELLOW -> B (V)
- BLACK  -> C (W)

Hall: click the 5-pin hall connector into the hall header. Hall only. Leave the
encoder input empty unless I've actually added an encoder module (if I did,
wire it and re-check this).

E-stop: for bench testing, jump the STOP terminals right on the board (it ships
jumpered, so just leave it). On the real rover this feeds into the main e-stop
line instead, so don't leave it board-jumpered once it's on the chassis.

VINT ports: plug the four controllers into the hub. I'm using ports 0 and 2
(or 0 and 1) for one pair, and 5 and 4 (or 5 and 3) for the other. Keeps the
cabling from turning into spaghetti.

Do NOT power up yet. Bring the motors online one at a time: wire one, test it
all the way through, then move to the next. Doing all four at once is how a
wiring mistake slips past you.

## Step 2 — is it even there

```
lsusb
```

Look for a Phidgets line (vendor `06c2`, shows up as the VINT Hub). If it's not
listed, it's a USB or cable problem. Fix that before touching anything else.

## Step 3 — permissions (Linux)

Skip this and every run needs sudo. One-time setup:

```
sudo tee /etc/udev/rules.d/99-libphidget22.rules > /dev/null <<'EOF'
SUBSYSTEM=="usb", ATTRS{idVendor}=="06c2", MODE="0666"
EOF
sudo udevadm control --reload-rules
sudo udevadm trigger
```

Then unplug and replug the hub's USB so the rule actually takes.

## Step 4 — confirm comms

```
python attach_test.py --serial <serial>
```

Prints the device name, serial, and hub port if the controller's alive. No
motion. This is proving USB -> hub -> VINT cable -> controller. If it says
access denied, Step 3 didn't take. If it says no matching devices, power's off
or the VINT cable is loose.

## Step 5 — spin it

Free the shaft first, set the bench supply current limit low (~2A), turn on the
24V, then:

```
python spin_test.py --serial <serial> --duty 0.1 --seconds 2
```

What I'm watching for:
- Smooth spin = phase and hall wiring are right.
- Stutter or cogging = phase/hall mismatch. Power off, fix it.
- Wrong direction = flip the sign of `--duty`. Software only, no rewiring.

Then repeat Steps 4 and 5 for each motor as I bring them online. Write down
which serial goes to which wheel. The ROS bridge addresses them by serial, so
I'll need that mapping later.

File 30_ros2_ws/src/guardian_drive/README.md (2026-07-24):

# guardian_drive

**Owner: Phillipp**

Mecanum wheel kinematics, the Phidgets motor bridge, and a dummy odometry source for driving GUARDIAN without hardware.

## Nodes

| Node | Purpose |
|---|---|
| `mecanum_kinematics_node` | Converts `/cmd_vel` Twist → 4x wheel RPM targets |
| `phidget_bridge_node` (owner: Vedant) | Drives the 4x Phidget DCC1120 controllers over VINT/USB, reads hall-based wheel velocity back, publishes `/odom` + TF. This is the node actually wired into `guardian.launch.py` for real hardware. |
| `serial_bridge_node` (alias `guardian_drive_node`) | Pre-Phidgets ESP32-over-serial bridge. Kept in the codebase but **not launched anywhere** — the robot no longer has ESP32 boards. |
| `dummy_odom_node` | Integrates `/cmd_vel` into fake `/odom` + TF, for testing without a connected drive base |

## Topics

| Topic | Type | Direction |
|---|---|---|
| `/cmd_vel` | `geometry_msgs/Twist` | Subscribed (all nodes) |
| `/wheel_rpm` | `std_msgs/Float32MultiArray` | Published by `mecanum_kinematics_node`, subscribed by `phidget_bridge_node` (FL, FR, BL, BR) |
| `/odom` | `nav_msgs/Odometry` | Published by `phidget_bridge_node` (real) or `dummy_odom_node` (sim/bench test) |

## How to Launch or Run

Normally brought up as part of `guardian_bringup` (`guardian.launch.py`, any mode). To run standalone:

```bash
ros2 run guardian_drive mecanum_kinematics_node
ros2 run guardian_drive phidget_bridge_node
# or, without hardware attached:
ros2 run guardian_drive dummy_odom_node
```

`phidget_bridge_node` degrades gracefully with no Phidget hub attached — it logs
"no controller on hub port N" per wheel and keeps running (motors just no-op,
`/odom` publishes zero), so the ROS-level wiring (params, `/wheel_rpm` in,
`/odom` out) can be sanity-checked on a bench with no hardware connected.

## Known Issues / Dependencies

- `phidget_bridge_node` addresses wheels by **VINT hub port**, not serial number — all 4 DCC1120 controllers share the hub's own serial (`hub_serial`, default `782265`), see the node's file header for the port map and the two bench calibration steps (`rescale_factor`, `wheel_directions`).
- `dummy_odom_node` and `phidget_bridge_node` both publish `/odom` — never run both at once.
- Depends on `tf2_ros` for the odom→base_link transform, and the `Phidget22` Python package + `libphidget22` for `phidget_bridge_node`.

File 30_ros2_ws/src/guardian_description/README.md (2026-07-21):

# guardian_description

Xacro/URDF robot model for GUARDIAN (no meshes checked in yet — placeholder geometry only).

## Nodes

None. This package only contains URDF/xacro and Gazebo world files.

## Topics

None directly — `robot_state_publisher` (launched from `guardian_bringup`) consumes this package's URDF to publish `/robot_description` and TF.

## Files

| File | Purpose |
|---|---|
| `urdf/guardian.urdf.xacro` | Single shared robot model for sim and real — `use_sim:=true/false` toggles the simulation-only `<gazebo>` blocks (MecanumDrive plugin, gpu_lidar sensors) |
| `urdf/dimensions.xacro` | AUTO-GENERATED by `20_hardware/cad/step_to_description.py` — measured wheel/lidar dimensions, don't hand-edit |
| `meshes/*.stl` | AUTO-GENERATED by the same script, from the CAD assembly |
| `worlds/guardian_world.sdf` | Gazebo simulation world |

## How to Use

Not run directly — included by `guardian_bringup`'s `guardian.launch.py` via `xacro`:

```bash
ros2 launch guardian_bringup guardian.launch.py                 # sim (default)
ros2 launch guardian_bringup guardian.launch.py use_sim:=false  # real hardware
```

When a new CAD revision replaces the current one:
```bash
python3 20_hardware/cad/step_to_description.py path/to/NewCAD.STEP
colcon build --symlink-install --packages-select guardian_description
```

## Known Issues / Dependencies

- Wheel base and wheel radius in the xacro must match `guardian_bringup/config/robot_params.yaml` after the physical build.
- No mesh files yet — visual/collision geometry is primitive shapes only.
- Must include T265 camera frame, LIDAR frame, and arm base frames for a correct TF tree once CAD is finalized.
- Depends on `xacro` for macro expansion at launch time.

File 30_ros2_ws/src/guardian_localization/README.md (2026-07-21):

# guardian_localization

**Owner: Phillipp**

LIDAR republishing and sensor preprocessing to feed Nav2 costmaps and the EKF.

## Nodes

| Node | Purpose |
|---|---|
| `lidar_republisher_node` | Republishes Scanse Sweep scan data onto the topic/frame Nav2 expects, with a small timestamp offset correction |

## Topics

| Topic | Type | Direction |
|---|---|---|
| `/sweep/scan` | `sensor_msgs/LaserScan` | Subscribed (default `input_topic`, from `l3xz_sweep_scanner`) |
| `/scan_filtered` | `sensor_msgs/LaserScan` | Published (default `output_topic`, consumed by Nav2 costmaps, SLAM Toolbox, and AMCL) |

## How to Launch or Run

Brought up as part of `guardian_bringup` (`guardian.launch.py`, any mode). To run standalone:

```bash
ros2 run guardian_localization lidar_republisher_node
```

### Self-occlusion masking (`mask_angle_ranges`)

If the LIDAR's mount permanently blocks part of its rotation (e.g. a wall or
post directly behind it), that sector reads a constant near-zero range —
left alone, SLAM/AMCL/costmaps would see it as a real, robot-attached
obstacle. Set `mask_angle_ranges` to blank those beams out (published as
`NaN`, which downstream consumers ignore rather than treat as an obstacle
or as clear space):

```yaml
lidar_republisher_node:
  ros__parameters:
    mask_angle_ranges: "2.356,-2.356"   # "lo1,hi1,lo2,hi2,..." in radians,
                                        # in the scan's own angle_min/angle_max
                                        # frame. Wraps across +-pi. Above
                                        # example blanks a ~90deg wedge
                                        # centered directly behind the sensor.
```

Empty string (default) = no masking, i.e. today's behavior is unchanged.

Because every parameter here (topics, frame_id, the mask) is per node
*instance*, a second physical LIDAR is just another `lidar_republisher_node`
launched with its own `name=`, `input_topic`/`output_topic`, and
`mask_angle_ranges` — no code changes needed.

## Known Issues / Dependencies

- `input_topic`, `output_topic`, `frame_id`, and `timestamp_offset_sec` are all parameters — check `guardian_bringup/config/robot_params.yaml` for the values actually used at launch.
- `mask_angle_ranges` is a comma-separated string, not a native double array — ROS2/rclpy (observed on Jazzy) mis-types a `double_array` parameter declared with an empty-list default when a non-empty override is applied later (`InvalidParameterTypeException`, override read back as `BYTE_ARRAY`), regardless of an explicit `ParameterDescriptor`. The string workaround sidesteps it.
- Depends on `l3xz_sweep_scanner` publishing `/sweep/scan` upstream.

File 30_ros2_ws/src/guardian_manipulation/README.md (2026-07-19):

# guardian_manipulation

**Owner: Dipam**

Dual SO-101 LeRobot arm management — follower arm control, LeRobot policy inference, and the Quest teleop bridge.

## Nodes

| Node | Purpose |
|---|---|
| `arm_manager_node` | Manages both SO-101 follower arms, coordinates dual-arm operation (stub — LeRobot init TODO) |
| `teleop_bridge_node` | Bridges Quest hand tracking input to LeRobot arm commands (stub — subscriber/publisher TODO) |

## Scripts

| Script | Purpose |
|---|---|
| `scripts/collect_training_data.py` | Records leader arm demonstrations for LeRobot imitation learning (stub) |

## Topics

Both nodes are currently stubs with all pub/sub commented out pending LeRobot integration. Planned:

| Topic | Type | Direction |
|---|---|---|
| `/quest/hand_poses` | `geometry_msgs/PoseArray` | Subscribed by `teleop_bridge_node` (planned) |
| `/arm_commands` | `std_msgs/Float32MultiArray` | Published by `teleop_bridge_node`, subscribed by `arm_manager_node` (planned) |
| `/arm_joint_states` | `sensor_msgs/JointState` | Published by `arm_manager_node` (planned) |

## How to Launch or Run

Not yet wired into a `guardian_bringup` launch file. Run standalone:

```bash
ros2 run guardian_manipulation arm_manager_node
ros2 run guardian_manipulation teleop_bridge_node
python3 src/guardian_manipulation/scripts/collect_training_data.py
```

## Known Issues / Dependencies

- Both nodes are unimplemented stubs (see inline `TODO`s) — no actual arm I/O yet.
- Requires the `lerobot` Python package (`pip install -e lerobot[feetech]`, not a rosdep-resolvable package — install manually, see `60_scripts/setup_amd_minipc.sh`).
- Hardware: 2x SO-101 follower arms over USB-C to the AMD MiniPC.
- See [40_lerobot/README.md](../../../40_lerobot/README.md) and [10_docs/setup/dependencies.md](../../../10_docs/setup/dependencies.md) for LeRobot setup.

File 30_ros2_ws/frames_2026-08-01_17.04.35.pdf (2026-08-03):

view_frames Result

Recorded at time: 1785618275.449509

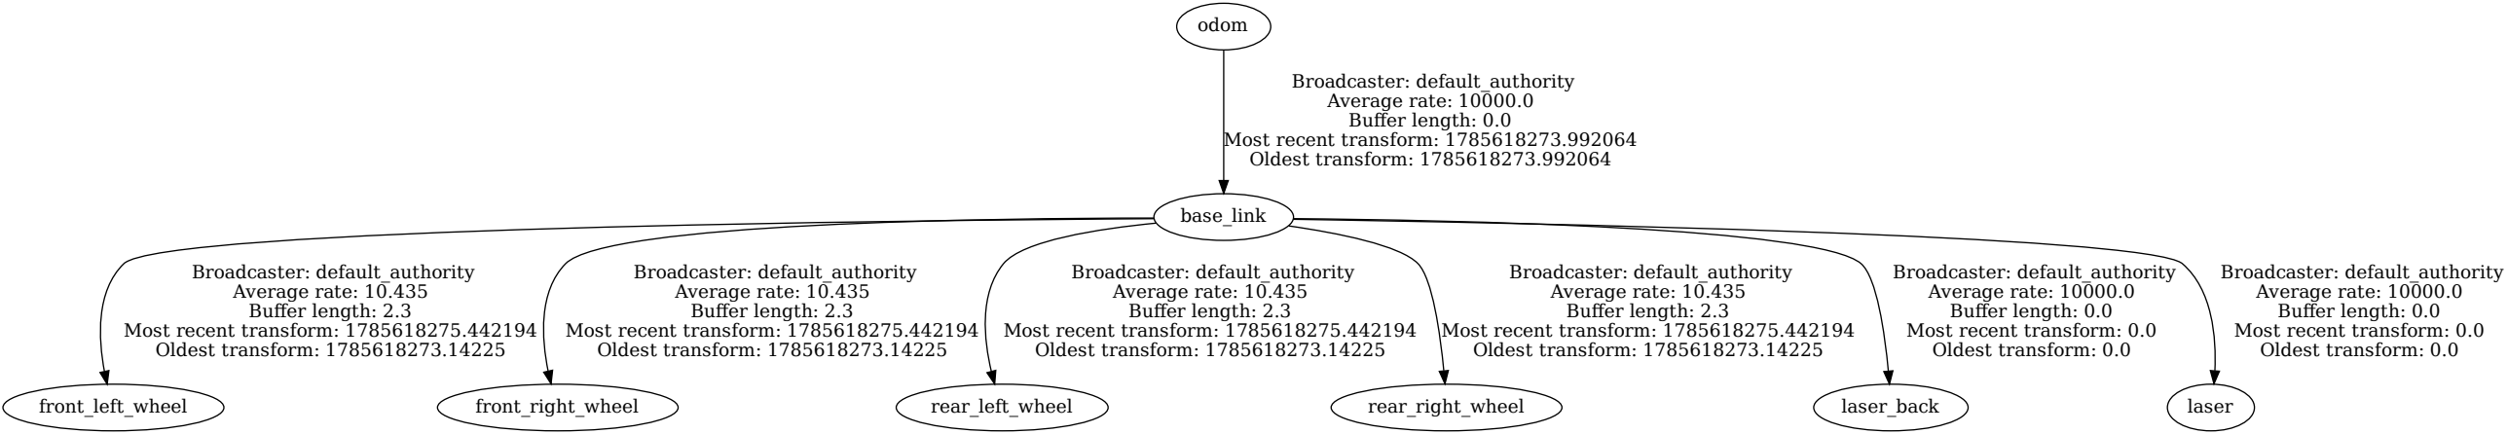
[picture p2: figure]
base_link; front_left_wheel; Broadcaster: default_authority Average rate: 10.435 Buffer length: 2.3 Most recent transform: 1785618275.442194 Oldest transform: 1785618273.14225; front_right_wheel; rear_left_wheel; rear_right_wheel; laser_back; Broadcaster: default_authority Average rate: 10000.0 Buffer length: 0.0 Most recent transform: 0.0 Oldest transform: 0.0; laser; odom; Broadcaster: default_authority Average rate: 10000.0 Buffer length: 0.0 Most recent transform: 1785618273.992064 Oldest transform: 1785618273.992064

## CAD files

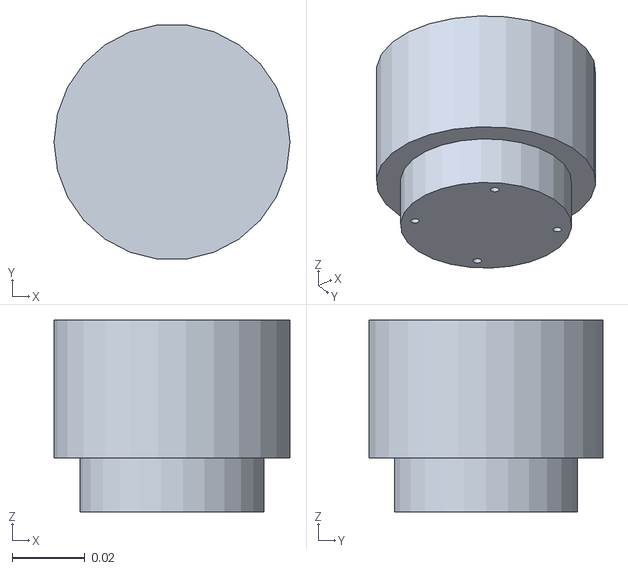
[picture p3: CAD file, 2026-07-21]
30_ros2_ws/src/guardian_description/meshes/lidar.stl
0.065 x 0.0645 x 0.0528

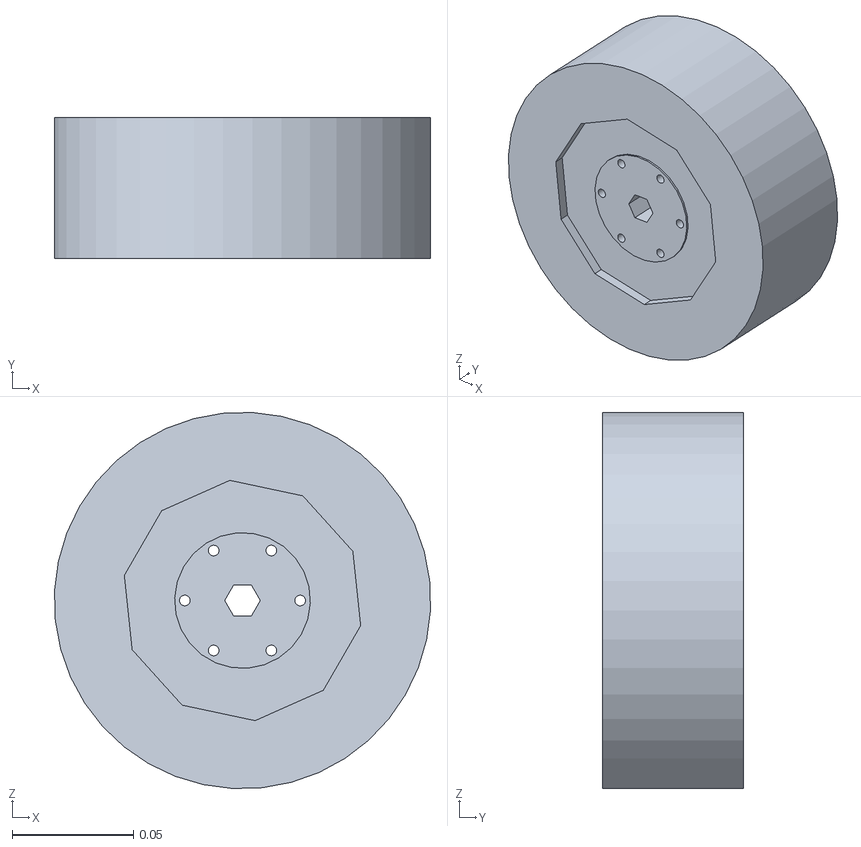
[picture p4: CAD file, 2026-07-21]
30_ros2_ws/src/guardian_description/meshes/wheel.stl
0.155 x 0.058 x 0.155

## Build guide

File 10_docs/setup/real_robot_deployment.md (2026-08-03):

# Real Robot Deployment — Boot-Time Web Control Interface

Step-by-step for getting the robot to boot up controllable from a browser,
with no SSH/monitor/keyboard needed. Run all of this **on the robot's own
mini PC**, not a dev/lab machine.

At the end: the mini PC boots → drive chain + LIDARs come up automatically
→ the browser control interface (Foxglove) is reachable over ZeroTier →
Nav2/SLAM only starts when you actually press a button.

## 1. Prerequisites

```bash
sudo apt update && sudo apt install -y ros-jazzy-foxglove-bridge
```

If `ros-jazzy-navigation2`, `ros-jazzy-nav2-bringup`, `ros-jazzy-slam-toolbox`
aren't already installed, see [amd_minipc_setup.md](amd_minipc_setup.md).

Also worth running once — out-of-sync `diagnostic_updater`/nav2 packages
have caused `nav2_lifecycle_manager` to crash with a symbol-lookup error
before:

```bash
sudo apt update && sudo apt upgrade -y
```

## 2. Pull and build

```bash
cd ~/GUARD.IAM_AutomousRover && git pull
cd 30_ros2_ws && colcon build --symlink-install
```

## 3. Test before committing to boot

```bash
guardiam_test_boot
```

(or `bash 60_scripts/systemd/test_services.sh` if `guardiam_env.sh` isn't
sourced yet — it should be, via `~/.bashrc`)

This installs the systemd `--user` units and starts them **now**, without
enabling boot-time auto-start. Verify, in order:

1. **Hardware**: `systemctl --user status guardian-hardware` shows
   `active (running)`. Motors respond to Xbox teleop. Both LIDARs publish
   (`ros2 topic hz /scan`, `/scan_back`).
2. **Browser connection**: from any device on the ZeroTier network, open
   `https://app.foxglove.dev`, connect to
   `ws://<mini-pc's-ZeroTier-IP>:8765`. The robot mesh renders (see
   §5 below if it doesn't — this is the one dev-machine-only step).
3. **Mode switching**: click 🗺️ Start Mapping, then 🧭 Start Navigation.
   Each should flip 🟢 Stack Ready to green within a few seconds.
4. **Goal-sending**: use the Publish panel (topic `/goal_pose`) to send a
   goal. The Log panel should show `Navigating — X.XXm remaining...`
   then `Idle` once it arrives.
5. **Waypoints**: drive somewhere, set `target_waypoint_index` to `0` in
   the Parameters panel, click ✓. The Log panel confirms the write.
6. **Demo**: 🚀 Start Demo drives through whatever's in `waypoints.yaml`.
7. **Save Map**: 💾 Save Map while mapping — confirm
   `30_ros2_ws/src/guardian_bringup/maps/guardian_map.{pgm,yaml}` updates.

If anything fails, fix it and re-run `guardiam_test_boot` — it's safe to
run repeatedly (`systemctl restart`, not `start`, so it always picks up
the latest build/unit files).

## 4. Commit to the boot sequence

Once everything above checks out:

```bash
guardiam_install_boot
```

This `systemctl --user enable --now`s the three always-on services
(hardware, foxglove_bridge, web_ops_node) and runs
`loginctl enable-linger` (one `sudo` prompt) — without linger, user
services only run while a login session is active, not from a cold boot
with nobody logged in.

`guardian-stack@.service` (Nav2/SLAM) is **not** enabled here on purpose —
only `guardian-hardware`, `guardian-foxglove-bridge`, and `guardian-ops`
start automatically. Nav2 only ever runs when you press Start
Mapping/Navigation from the browser.

## 5. Reboot and verify

```bash
sudo reboot
```

Wait ~30s, then from a browser: `ws://<mini-pc's-ZeroTier-IP>:8765`. If it
connects and the buttons work with nobody having logged into the mini PC
since reboot, boot persistence is confirmed.

## 6. Foxglove layout — do this once, on any machine connecting for the first time

The Foxglove **layout** (panel arrangement) is separate from the robot
setup above — it lives in your Foxglove account, not on the robot. If
you're setting up a fresh browser/account:

- **3D panel** → Settings → Scene → **Mesh up-axis: Z-up** (do this
  *before* adding the URDF layer — see known-issues note below).
- Custom Layers → **+ Add → URDF** → Source: Topic, Topic:
  `/robot_description`, Control mode: Transforms.
- Settings → Topics → toggle `/map`, `/plan`, `/plan_smoothed` visible.
- Settings → Frame → **Display frame: map** (not `base_link` — goals
  published from the wrong frame get silently rejected by `bt_navigator`).
- Add panel → **Publish**, topic `/goal_pose`
  (`geometry_msgs/msg/PoseStamped`) for sending Nav2 goals.
- Add panel → **Service Call** ×4, one each for `/guardian/save_map`,
  `/guardian/switch_to_mapping`, `/guardian/switch_to_navigation`,
  `/guardian/start_demo`.
- Add panel → **Indicator**, expression `/guardian/stack_ready.data`,
  rule `= true` → green "Ready".
- Add panel → **Log**, then in its Namespaces filter hide
  `foxglove_bridge`/`gz_bridge` (chatty, unrelated) — shows
  `nav_status_node` and `set_waypoint_node` confirmations cleanly.
- Add panel → **Parameters**, filter to `target_waypoint_index` — type an
  index, click the ✓ to record the robot's current pose there.

Full rationale for each of these is in
[web_control_interface_setup.md](web_control_interface_setup.md) if
something doesn't behave as expected.

## Known issues to watch for

- **URDF mesh sometimes vanishes on a mode switch, even though the
  backend is fine.** Reload the browser tab — this has reliably fixed it
  every time it's happened. Not a robot-side problem.
- **A long-running `ros2` CLI daemon can go stale** after enough
  restarts/kills and cause Nav2 nodes to look alive via `ps` but never
  actually configure (`activate_lifecycle_node.sh` loops
  `Node not found`). Fix: `ros2 daemon stop` (auto-restarts fresh on the
  next `ros2` command).
- **First-ever boot against real Phidgets/LIDARs is untested as of this
  writing** — everything above was validated in sim. Budget extra time
  for the first real run of §3.

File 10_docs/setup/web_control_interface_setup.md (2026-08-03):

# Browser Control Interface Setup (Foxglove)

What this gives you: open a browser anywhere on the ZeroTier network (no
SSH, no monitor/keyboard on the robot), see the robot's 3D view + live map,
send Nav2 goals, and press buttons to start mapping, start navigation, or
save the map — all against hardware that auto-starts the moment the mini
PC boots.

Everything below was built and verified **in sim, on a lab PC** (not the
real robot), end-to-end, not just eyeballed:
- Robot mesh + map rendering — confirmed correct against Gazebo's own
  native render.
- 🗺️ Start Mapping / 🧭 Start Navigation / 💾 Save Map buttons — each
  tested by actually clicking them; each does the real thing (verified
  via `systemctl` state and `git diff` on the saved map).
- Nav goal sending — tested by watching `bt_navigator`'s log show `Begin
  navigating from current location (...) to (x, y)` and confirming the
  robot's `/odom` position actually reached the target.

The hardware-launch path (`guardian_hardware.launch.py`,
`guardian-hardware.service`) is written and logically consistent with how
the rest of the stack already works, but has **not been run against real
Phidgets/LIDARs yet** — that first real run is tomorrow's job.

## 1. Prerequisites — install once on the mini PC

```bash
sudo apt update && sudo apt install -y ros-jazzy-foxglove-bridge
```

(If `ros-jazzy-navigation2`, `ros-jazzy-nav2-bringup`, `ros-jazzy-slam-toolbox`,
`ros-jazzy-ros-gz` aren't already on the mini PC, install those too — see
`10_docs/setup/amd_minipc_setup.md`.)

Also worth doing once, if `diagnostic_updater` and friends aren't in sync
with the nav2 packages (this bit us on the lab PC — `nav2_lifecycle_manager`
crashed with a symbol-lookup error until this was run):

```bash
sudo apt update && sudo apt upgrade -y
```

## 2. Pull the code and build

```bash
cd ~/GUARD.IAM_AutomousRover
git pull
cd 30_ros2_ws
colcon build --symlink-install
```

## 3. Install the systemd services

```bash
bash 60_scripts/systemd/install_services.sh
```

This installs 4 **user-level** systemd units (no root needed for the
services themselves — only `loginctl enable-linger` at the end needs
`sudo`, so it's a one-time password prompt):

| Unit | Starts at boot? | What it does |
|---|---|---|
| `guardian-hardware.service` | Yes | Drive chain (mecanum + Phidget bridge) + both LIDARs. **Not yet tested on real hardware.** |
| `guardian-foxglove-bridge.service` | Yes | `foxglove_bridge` on port 8765, bound to `0.0.0.0` (reachable over ZeroTier) |
| `guardian-ops.service` | Yes | `web_ops_node` — exposes the 3 buttons described below |
| `guardian-stack@.service` | No (started on demand) | The actual Nav2/SLAM stack, `mode:=mapping` or `mode:=navigation`. Started/stopped by the ops node, not by systemd directly. |

Check they're up:

```bash
systemctl --user status guardian-hardware guardian-foxglove-bridge guardian-ops
```

## 4. Connect from a browser

From any device on the same ZeroTier network:

1. Go to `https://app.foxglove.dev` (sign in if needed).
2. **Open connection** → enter `ws://<mini-pc's ZeroTier IP>:8765`.
3. If it won't connect: check `foxglove_bridge` is actually running
   (`systemctl --user status guardian-foxglove-bridge`), and double check
   you're using the ZeroTier IP, not `localhost` (that only works if
   you're on the mini PC itself).

## 5. Build the layout (one-time, then it auto-saves)

**3D panel** (usually there by default):
- Settings → **Scene** → **Mesh up-axis** = `Z-up`. **Do this first,
  before adding the URDF layer.** Foxglove's 3D panel defaults this to
  `Y-up`, which silently rotates every mesh (chassis, wheels, LIDARs) 90°
  off its true axis — RViz has no such setting/default mismatch, which is
  why the same URDF rendered correctly there but not here. This is a
  per-panel client-side setting, completely independent of the URDF/TF
  data (which is correct either way) — it explains why *all* meshes were
  affected identically (a global panel setting, not a per-mesh bug) and
  why it has nothing to do with `step_to_description.py` or
  `guardian.urdf.xacro` (both untouched, confirmed via `git diff`). If
  you add the URDF layer before fixing this, or fix this while the layer
  errors out, Foxglove can get stuck showing a spurious `Invalid topic:
  '/robot_description'` error even with the topic correctly selected —
  if that happens, delete the URDF custom layer, reload the page (not
  just the panel), then re-add it fresh.
- Settings → **Custom Layers** → **+ Add** → **URDF**. Set **Source** =
  `Topic`, **Topic** = `/robot_description`, **Control mode** =
  `Transforms`. This renders the actual robot mesh (chassis, wheels,
  LIDARs) — confirmed working, meshes load automatically over the
  websocket (`foxglove_bridge` ≥ v0.7 fetches `package://` assets itself,
  no extra config needed).
- Settings → **Topics** → toggle `/map` visible (the eye icon on the
  right of the row) — this is the actual occupancy grid, separate from
  the "Map" custom layer (which is for satellite/street tiles, not this).
- Settings → **Transforms** → turn **Labels** off (the floating
  `front_left_wheel` etc. text is clutter once the mesh renders) and set
  **Follow mode** = `Position` (not `Pose (position + attitude)` — that
  one tilts the camera to match the robot's exact roll/pitch, which looks
  like a broken/tilted view even though nothing is actually wrong).
- Settings → **Frame** → **Display frame** = `map`, not `base_link`. This
  isn't just a camera setting — it's also the `frame_id` Foxglove stamps
  on anything you publish from the 3D view's click tools. With it left on
  `base_link`, `bt_navigator` rejects every click-published goal with
  `Failed to transform a goal pose provided with frame_id 'base_link' to
  the global frame 'map'` (confirmed in the systemd journal). `Follow
  mode: Position` still works fine with `Display frame: map` — the camera
  just stays map-anchored instead of chasing the robot, which is actually
  the more useful view for placing goals anyway.
- Settings → **Publish** → **2D pose** section → change the topic from
  the default `/move_base_simple/goal` (a ROS1 convention Foxglove ships
  as the default) to **`/goal_pose`** — that's what `bt_navigator`
  actually listens on here (confirmed against `nav2_params.yaml`, no
  remap configured).

**Goal-setting: use a Publish panel, not the 3D view's click tool.**
This was the hardest bug of the night. The 3D view's interactive
"Publish 2D pose" tool (right-click the pose icon in the 3D panel
toolbar → pick the mode → click-drag in the scene) creates a **brand
new, ephemeral DDS publisher on `foxglove_bridge` every time you use
it**, and publishes immediately — before DDS discovery has finished
matching that fresh publisher to `bt_navigator`'s subscriber. The
message gets sent, `ros2 topic echo` can even catch it (a generic
subscriber matches fast enough), but `bt_navigator` specifically misses
it more often than not. No error, no log line — the goal just silently
never arrives. Confirmed by directly checking `ros2 topic info
/goal_pose --verbose`: two separate `foxglove_bridge` publisher GIDs
existed after only two clicks, and neither publish showed up in
`bt_navigator`'s log even after waiting 10+ seconds in a completely idle
system.

The fix: **Add panel → Publish** (not the 3D view tool). Configure once:
Topic = `/goal_pose`, it auto-detects the schema
(`geometry_msgs/msg/PoseStamped`). Edit the JSON body's `pose.position.x`
/ `y` and `header.frame_id: "map"`, then hit the panel's own **Publish**
button. This panel's publisher is created once when the panel is added
and stays alive, so there's no per-click discovery race — confirmed
working end-to-end repeatedly: `bt_navigator` logs `Begin navigating from
current location (...) to (x, y)` immediately, and the robot's `/odom`
position was verified to actually reach the target. Title the panel
something like "🎯 Send Nav Goal (edit x/y, then Publish)" so it's
obvious how to use it without re-deriving this.

**Three Service Call panels** (Add panel → Service Call, once per button).
Each one: click the panel's own title bar first to make sure the sidebar
is actually editing *that* panel before typing (Foxglove's settings
sidebar doesn't always follow panel focus reliably — verify the Service
name field is empty before typing into it, or you'll silently overwrite
a different panel's config):

| Service name | Button title |
|---|---|
| `/guardian/switch_to_mapping` | 🗺️ Start Mapping |
| `/guardian/switch_to_navigation` | 🧭 Start Navigation |
| `/guardian/save_map` | 💾 Save Map |
| `/guardian/start_demo` | 🚀 Start Demo |

All four were tested by actually clicking them (not just configured) —
each returns `success: true` and does the real thing (switches the
running systemd unit instance, saves+rebuilds the map, or launches
`demo_mission_node` via `subprocess.Popen` — fire-and-forget, not
`.run()`, since the demo runs for minutes and a blocking call here would
freeze `web_ops_node` itself for that whole time, same failure mode
`_save_map` used to have; a second click while one's already running
returns `success: false` with the running PID instead of stacking a
duplicate).

**Path, status, and waypoint recording** — three more additions, all
served by `nav_status_node` and `set_waypoint_node` (started
automatically alongside the rest of Nav2 core, in both mapping and
navigation mode):

- **Planned path**: Settings → **Topics** → toggle `/plan` (global) and
  `/plan_smoothed` visible in the 3D panel — Nav2 already publishes
  these, no code needed.
- **Nav status + readiness**: `nav_status_node` publishes two latched
  topics — `/guardian/nav_status` (`std_msgs/String`, re-publishing
  `NavigateToPose`'s action feedback — `distance_remaining` and
  `estimated_time_remaining` are already computed by Nav2, nothing to
  calculate ourselves) and `/guardian/stack_ready` (`std_msgs/Bool` —
  true once `controller_server` and `bt_navigator` both report lifecycle
  state `active`, i.e. actually safe to send a goal or start the demo;
  polled via the same `GetState` service calls
  `nav2_simple_commander.waitUntilNav2Active()` uses internally, so it
  works the same in mapping mode too, unlike checking `amcl` directly).
  Both also go through `get_logger()` on every *change* (not every
  feedback tick — that would spam), so **Add panel → Log**, then in the
  panel's Namespaces list hide `foxglove_bridge`/`gz_bridge` (chatty,
  unrelated), gives a clean timestamped status feed for free instead of
  raw JSON in a Raw Messages panel. Separately, **Add panel → Indicator**
  with Expression `/guardian/stack_ready.data` (rule `= true` → green
  "Ready", fallback → gray "Not Ready") gives an at-a-glance readiness
  light.
- **Waypoint recording from the browser**: `set_waypoint_node` now runs
  in two modes from the same script — the original one-shot CLI
  (`set_waypoint <index>` / `--ros-args -p index:=N`, unchanged) *and*,
  when launched with no `index` param (which is how `guardian.launch.py`
  starts it), a persistent listener on `/guardian/set_waypoint_index`
  (`std_msgs/Int32`). **Add panel → Publish**, Topic =
  `/guardian/set_waypoint_index`, schema auto-detects as `std_msgs/Int32`
  — drive the robot to where waypoint `N` should be, edit `data` to `N`,
  hit Publish, same one-action feel as the CLI alias. Confirmation
  (or the "no transform available" error, if localization isn't up yet)
  shows up in the same Log panel as nav_status, no extra topic needed.

## Known issues / things to double check tomorrow

- **URDF mesh sometimes vanishes on a mode switch (mapping↔navigation),
  even though `/robot_description`, TF, and the URDF layer's own config
  are all fine.** Confirmed on the backend: `robot_state_publisher` never
  restarts on a mode switch (it lives in `guardian_sim.launch.py`, not
  `guardian.launch.py`), `/robot_description` stays latched with the same
  single publisher throughout, and every wheel/laser TF frame keeps
  updating — none of that explains the mesh disappearing, and the URDF
  layer shows no error icon when it happens (unlike the earlier `Invalid
  topic` corruption, which did). This looks like a Foxglove-client-side
  rendering hiccup triggered by the burst of ~15 nodes stopping/starting
  within a couple seconds during a mode switch — outside anything fixable
  from this repo. **Workaround**: reload the browser tab. Confirmed this
  reliably brings the mesh back (not just a coincidence — reproduced and
  fixed this exact way twice in one session). If it recurs after a mode
  switch, reload first before assuming something is actually broken.
- **A long-running `ros2` CLI daemon can go stale and cause very
  confusing failures that look like real Nav2 bugs.** One evening's worth
  of `kill_ros.sh` sweeps and node restarts left the daemon (started
  hours earlier, `ros2 daemon status` / `pgrep -f ros2cli.daemon`) with a
  stale view of the graph: `ros2 node list` stopped showing `map_server`/
  `amcl` at all, even though both were alive and directly
  service-callable. This silently broke `activate_lifecycle_node.sh`'s
  own node-existence check (`ros2 node info <name>`, which goes through
  the same daemon), so it looped `Node not found` forever and never
  configured either node — `map_server`/`amcl` stuck at lifecycle state
  `unconfigured` indefinitely, `demo_mission_node` hanging forever on
  `amcl/get_state service not available, waiting...`, `planner_server`
  failing to activate its costmap ("transform from base_link to map did
  not become available"). **Fix**: `ros2 daemon stop` (it auto-restarts
  fresh on the next `ros2` CLI invocation and immediately sees the
  correct graph). If Nav2 nodes look alive via `ps`/`journalctl` but
  `activate_lifecycle_node.sh` keeps saying `Node not found`, or a
  service is directly callable but doesn't show up in `ros2 node list`,
  suspect a stale daemon before assuming a real Nav2/DDS problem.
- **`kill_ros.sh`'s force-kill pattern used to be a hand-enumerated list
  of binary names, and kept missing new orphans** — `nav2_*` executables,
  `teleop_twist_joy`'s actual `teleop_node` binary, `ros_gz_bridge`'s
  actual `parameter_bridge` binary, and even plain
  `robot_state_publisher` each individually slipped past earlier versions
  of the pattern (a process's *ROS node name* is very often just a
  `--ros-args -r __node:=` remap with nothing to do with its binary's
  actual filename). One `parameter_bridge` orphan survived 45+ minutes
  and multiple `kill_ros.sh` runs this way, ending up as a second live
  publisher on `/scan`/`/odom`/`/tf`/`/clock` racing a freshly-launched
  one. Fixed by matching `--ros-args` generally (every rclpy/rclcpp node
  gets this flag appended regardless of binary name) instead of
  enumerating binaries — a real fix, not another name added to the list.
- **Real hardware not yet tested.** `guardian-hardware.service` has never
  run against actual Phidgets/LIDARs. First boot on the mini PC is the
  real test.
- **Chassis/wheel/LIDAR mesh orientation — resolved, no code change
  needed.** Root cause: Foxglove 3D panel's **Mesh up-axis** setting
  defaults to `Y-up`; ROS/URDF meshes are `Z-up`. Fixed by the Scene
  setting documented in section 5 above — this is a **per-layout
  setting** (saved with the layout, not per-robot or per-mesh), so it
  only needs to be set once when building the layout, and will still be
  correct "the moment we have a new STL file" since it has nothing to do
  with mesh content. Verified from multiple camera angles (top-down,
  oblique, and a close-up side profile) — wheel cylinders' rotation axis
  correctly aligns with their joint's TF axis, chassis frame renders
  rectangular and level, not skewed. `step_to_description.py` and
  `guardian.urdf.xacro` are both untouched at their original committed
  state — confirmed via `git diff` — and should stay that way; this was
  never a mesh-generation or URDF bug.
- **`kill_ros.sh`** was patched this session — its force-kill pattern
  didn't match Nav2's own executables (`nav2_controller`,
  `bt_navigator`, etc., which live under `/opt/ros/*/lib/nav2_*/` and
  don't match any of the script's other patterns), so they could survive
  as orphans after a SIGINT-only shutdown. Fixed by adding `nav2_` to the
  pattern — if you see orphaned Nav2 processes after a shutdown, that's
  the symptom to check for.
- **`ROS_DOMAIN_ID` consistency matters**: every launch (hardware, stack,
  foxglove_bridge, ops node, and any manual `ros2` CLI you run to debug)
  needs to go through `guardiam_env.sh` (which sets `ROS_DOMAIN_ID=42`).
  Mixing a domain-42 process with a domain-0 shell makes them invisible
  to each other with no obvious error — this cost real debugging time
  this session.
- **`save_map.sh`** was fixed this session — it used to break when
  invoked via its *installed* (symlinked) path instead of directly from
  source, because it didn't resolve the symlink chain before computing
  its own directory. Already fixed in the committed script; mentioned
  here so nobody "fixes" it back if the symptom resurfaces elsewhere.
- **Don't put `Restart=on-failure` on a sim/test `guardian-stack@.service`
  unit.** Doing that during testing meant every manual `pkill`/cleanup
  attempt got silently undone by systemd relaunching Gazebo behind our
  back — repeated enough times over one evening to exhaust both RAM and
  swap (`free -h` showed 37 of 39 GB of swap in use), which then caused
  real, confusing symptoms (goal delivery lag, sluggish everything) that
  had nothing to do with any actual code bug. The committed
  `60_scripts/systemd/guardian-stack@.service` (the real-hardware one)
  correctly has no `Restart=` directive for this exact reason — leave it
  that way. If you're improvising a local test unit by hand, don't add
  auto-restart to it either.
- **After a long testing session, check `free -h` before trusting any
  "it's not working" symptom.** Swapped-out memory makes IPC/DDS
  discovery slow and inconsistent in ways that look exactly like
  application bugs. `pkill`/`kill_ros.sh` cleanup between test rounds
  matters more than it seems.

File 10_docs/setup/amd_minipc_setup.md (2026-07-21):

# AMD Ryzen AI MiniPC Setup

## Prerequisites

- AMD Ryzen AI MiniPC
- USB keyboard + HDMI monitor (for initial OS install)
- USB drive with Ubuntu 22.04 LTS image

## Steps

### 1. Install Ubuntu 22.04 LTS

Flash Ubuntu 22.04 LTS to a USB drive and boot the MiniPC from it. Follow the installer — use the entire disk, create a user named `guardian` for consistency.

### 2. Install ROS2 Humble

```bash
# Add ROS2 apt repository
sudo apt install software-properties-common curl -y
sudo curl -sSL https://raw.githubusercontent.com/ros/rosdistro/master/ros.key \
  -o /usr/share/keyrings/ros-archive-keyring.gpg
echo "deb [arch=$(dpkg --print-architecture) signed-by=/usr/share/keyrings/ros-archive-keyring.gpg] \
  http://packages.ros.org/ros2/ubuntu $(. /etc/os-release && echo $UBUNTU_CODENAME) main" \
  | sudo tee /etc/apt/sources.list.d/ros2.list > /dev/null
sudo apt update
sudo apt install ros-jazzy-desktop -y
```

### 3. Install colcon and rosdep

```bash
sudo apt install python3-colcon-common-extensions python3-rosdep -y
sudo rosdep init
rosdep update
```

### 4. Clone GUARDIAN Repository

```bash
git clone https://github.com/PhillippGery/GUARDIAN.git ~/GUARDIAN
```

### 5. Run Automated Setup Script

```bash
cd ~/GUARDIAN
bash 60_scripts/setup_amd_minipc.sh
```

This script installs all ROS2 packages, Python dependencies, udev rules, and adds your user to the `dialout` group.

### 6. Connect Intel RealSense T265

Plug the T265 into a **USB 3.0** port (blue connector). Verify detection:

```bash
rs-enumerate-devices
```

### 7. Connect Scanse Sweep LIDAR

Plug the Sweep into a USB port. Confirm it appears:

```bash
ls /dev/ttyUSB*
# Expected: /dev/ttyUSB0
```

### 8. Connect Arduino Mega

Plug the Arduino Mega USB into another port. Confirm:

```bash
ls /dev/ttyUSB* /dev/ttyACM*
# Expected: /dev/ttyACM0 or /dev/ttyUSB1
```

Update `robot_params.yaml` if the port differs from `/dev/ttyUSB0`.

### 9. Connect SO-101 Arms

Plug both SO-101 follower arms into separate USB-C ports. Verify with `lsusb`.

### 10. Launch GUARDIAN

```bash
source /opt/ros/jazzy/setup.bash
source ~/GUARDIAN/30_ros2_ws/install/setup.bash
ros2 launch guardian_bringup guardian.launch.py use_sim:=false
```

Or use the menu script:

```bash
bash ~/GUARDIAN/60_scripts/run_guardian.sh
```

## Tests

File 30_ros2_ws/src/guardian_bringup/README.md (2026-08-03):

# guardian_bringup

**Owner: Phillipp**

Launch files and YAML/RViz/BT configuration that assemble the other GUARDIAN packages into runnable robot modes — no nodes of its own.

## Nodes

None. This package only contains launch files and config.

## Topics

None published or subscribed directly — see the launch files below for which packages/nodes are brought up.

## Launch Files

| File | Purpose |
|---|---|
| `guardian_hardware.launch.py` | **Real hardware only.** Everything physically attached to the robot: robot/joint state publishers, the drive chain (`mecanum_kinematics_node`, `phidget_bridge_node`), both Sweep LIDARs + republisher/merger chain, and Xbox teleop. No arguments, no mode — always the same, always on. Every node has `respawn=True`, so this is meant to be started once and left running for the whole session; if a USB glitch or flaky LIDAR connector kills a node, `ros2 launch` brings it back on its own. |
| `guardian.launch.py` | The software stack: Nav2, SLAM (mapping) or AMCL+map_server (navigation), RViz. In sim this is still the single entry point (Gazebo, gz bridge, robot description, and teleop are all included here too, since sim doesn't need the hardware split). On real hardware it launches **none** of the physical robot — it assumes `guardian_hardware.launch.py` is already running separately, so this file can be killed and relaunched freely while iterating on nav2/SLAM params without ever dropping the LIDAR/motor/teleop connections. |

On real hardware, start `guardian_hardware.launch.py` first and leave it running; `guardian.launch.py use_sim:=false ...` on top of it is what you'll actually kill/relaunch while testing.

```bash
# Sim, autonomous navigation, RViz open (defaults) — single launch, as before
ros2 launch guardian_bringup guardian.launch.py

# Real hardware — two terminals:
ros2 launch guardian_bringup guardian_hardware.launch.py            # once, leave running
ros2 launch guardian_bringup guardian.launch.py use_sim:=false mode:=mapping    # build a map
# ...or, once a map exists:
ros2 launch guardian_bringup guardian.launch.py use_sim:=false                  # navigation

# Headless (no RViz) — e.g. autonomous/unattended startup
ros2 launch guardian_bringup guardian.launch.py use_sim:=false rviz:=false

# Sim mapping mode, but with manual teleop override enabled too
ros2 launch guardian_bringup guardian.launch.py teleop:=true
```

Key arguments on `guardian.launch.py`: `use_sim` (`true`/`false`, default `true`),
`mode` (`mapping`/`navigation`, default `navigation`), `rviz` (default `true`),
`teleop` (**sim only** — real hardware teleop is always on via
`guardian_hardware.launch.py`, no flag needed; `true`/`false` explicitly overrides
in sim, left empty auto-selects mode-based: on for mapping, off for navigation),
`map` (map yaml to load in navigation mode), `known_pose` (auto: known spawn
point in sim, AMCL global localization on real hardware), `world`/`spawn_x`/
`spawn_y`/`spawn_z` (sim only). See `guardian.launch.py`'s `DeclareLaunchArgument`
calls for the full list and descriptions. `guardian_hardware.launch.py` takes
no arguments at all.

The aliases in `60_scripts/guardiam_env.sh` (`guardiam_sim`, `guardiam_hw`,
`guardiam_map`, `guardiam_real`) wrap the common cases — `guardiam_hw` is the
real-hardware launch, run it first.

## Xbox Controller Controls

Teleop is an Xbox controller via the standard `joy` + `teleop_twist_joy`
packages (config: `xbox_teleop.yaml`), not GUARDIAN's own keyboard node.
Connect over USB or Bluetooth — both work, USB is more reliable.

| Control | Action |
|---|---|
| **LB** (hold) | Deadman switch — nothing moves unless this is held, matching the old keyboard teleop's "only while held" safety |
| Left stick vertical | Forward / backward |
| Left stick horizontal | Strafe left / right |
| Right stick horizontal | Rotate |

Button/axis numbers were verified empirically (`buttons`/`axes` indices vary
by controller and driver, don't trust the "standard" xpad numbering blindly):
`enable_button: 6` (LB), `axis_linear.x: 1` (left stick Y), `axis_linear.y: 0`
(left stick X), `axis_angular.yaw: 2` (right stick X).

**No turbo currently** — RB was meant to be the turbo button
(`enable_turbo_button`), but on this controller/driver combo RB's button
press reaches the kernel fine (raw evdev shows `BTN_TR` firing) yet never
appears in `joy_node`'s published `/joy` message at all. Root cause not
found yet; `enable_turbo_button` is set to `-1` (disabled) rather than
pointing at a button that silently never fires. Speed scales in
`xbox_teleop.yaml` (`scale_linear`, `scale_angular`) are a fixed ~0.55 of
the real 170 RPM-rated max — bump those if turbo gets fixed, or just to
drive faster in the meantime.

## Config Files

| File | Purpose |
|---|---|
| `ekf_params.yaml` / `ekf_params_real.yaml` | robot_localization EKF configuration (sim / real) |
| `nav2_params.yaml` | Nav2 navigation stack parameters — one file for both sim and real (a separate `nav2_params_real.yaml` used to exist but was never wired into the launch file and had drifted stale; deleted) |
| `robot_params.yaml` | Robot geometry, serial port, hardware params (single source of truth via a `/**` wildcard block) |
| `lidar_filter_params.yaml` | Per-sensor LIDAR self-occlusion masking (front/back) |
| `xbox_teleop.yaml` | `teleop_twist_joy` axis/button mapping and speed scales for the Xbox controller |
| `navigate_to_pose.xml` | Nav2 behavior tree for `navigate_to_pose` |
| `guardian.rviz` | RViz display config — one file for both mapping and navigation mode, since Nav2 core runs in both |

## Known Issues / Dependencies

- `bt_navigator` needs `wait_for_service_timeout: 3000` in `nav2_params*.yaml` or it fails to find `behavior_server` on slower hardware.
- `behavior_server` must be listed before `bt_navigator` in the `node_names` array of the lifecycle manager config.
- `autostart: true` in the Nav2 params — the Nav2 lifecycle starts automatically on launch, no manual "Startup" click needed.
- Depends on `guardian_description`, `guardian_drive`, `guardian_localization`, `guardian_manipulation`, `guardian_navigation`, plus `joy`, `teleop_twist_joy`, `nav2_bringup`, `robot_localization`, `slam_toolbox`, `l3xz_sweep_scanner`, `rviz2`, `xacro`.
- Teleop is Xbox controller based (`joy` + `teleop_twist_joy`, config in `xbox_teleop.yaml`) — GUARDIAN's own `guardian_teleop` keyboard node is no longer wired into either launch file (kept in the codebase, just unused here). On real hardware it's launched unconditionally by `guardian_hardware.launch.py`, always on with no flag to remember.
- RealSense D415 camera node removed (was `realsense2_camera` in the real-hardware launch branch) — the pinned realsense-ros release doesn't support ROS_DISTRO=jazzy and broke full-workspace builds. Re-add once a Jazzy-compatible release exists upstream.

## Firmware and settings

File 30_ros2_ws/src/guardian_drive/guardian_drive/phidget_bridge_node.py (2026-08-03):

# MIT License
# GUARDIAN — GUARD.IAM
# Node: phidget_bridge_node
# Owner: Vedant
#
# Purpose: low-level drive bridge. Subscribes to /wheel_rpm (four wheel speed
#          targets from mecanum_kinematics_node), drives the Phidget DCC1120
#          BLDC controllers over VINT/USB using their built-in closed-loop
#          velocity controllers, reads hall-based wheel velocity back, and
#          publishes /odom plus the odom->base_link TF.
#
#          This is the phidget22 wrapper: it wraps Phidgets' own Python library
#          and exposes it to ROS. Drop-in replacement for serial_bridge_node —
#          same /wheel_rpm input, same [FL, FR, BL, BR] order, same RPM units,
#          same /odom output, so nothing upstream changes.
#
# ── ADDRESSING (important) ───────────────────────────────────────────────────
#   VINT devices report the serial number of the HUB they're plugged into, not
#   one of their own. All four DCC1120s share serial 782265 (the hub). What
#   distinguishes them is the HUB PORT. So wheels are addressed by hub port.
#
#   Nothing can auto-detect which wheel is on which port — that's physical, it's
#   which socket the cable is in. So the map is declared in config, and the node
#   scans at startup and drives whatever is actually present.
#
#   Current map:  FL = hub port 0,  FR = hub port 5,
#                 BL = hub port 2,  BR = hub port 3.
#   Set a wheel's port to -1 to skip it (useful for one-wheel bring-up).
#
# ── Two things still to calibrate on the bench ───────────────────────────────
#   1. rescale_factor  — makes the controller speak wheel RPM (see note below).
#   2. wheel_directions — per-wheel sign so +RPM drives that corner forward.
#      Left and right motors are mirror-mounted, so they take opposite signs.
#      Get all four right BEFORE trusting strafing: one wrong sign makes
#      diagonal motion fail in ways that look like a kinematics bug.

import math

import rclpy
from rclpy.node import Node
from std_msgs.msg import Float32MultiArray
from nav_msgs.msg import Odometry
from geometry_msgs.msg import TransformStamped
from tf2_ros import TransformBroadcaster

from Phidget22.Devices.MotorVelocityController import MotorVelocityController
from Phidget22.PhidgetException import PhidgetException

FL, FR, BL, BR = 0, 1, 2, 3
WHEEL_NAMES = ['FL', 'FR', 'BL', 'BR']


class PhidgetBridgeNode(Node):
    def __init__(self):
        super().__init__('phidget_bridge_node')

        # ── Addressing ───────────────────────────────────────────────────────
        # Serial of the VINT HUB (not the controllers). 0 = don't care.
        self.declare_parameter('hub_serial', 782265)
        # VINT hub port per wheel, order [FL, FR, BL, BR]. -1 = not wired yet.
        self.declare_parameter('wheel_hub_ports', [0, 5, 2, 3])
        self.declare_parameter('channel', 0)
        self.declare_parameter('attach_timeout_ms', 3000)

        # Per-wheel sign. Mirror-mounted motors need opposite signs left/right.
        self.declare_parameter('wheel_directions', [1, -1, 1, -1])

        # RESCALE FACTOR
        # The DCC1120's native velocity unit on hall feedback is commutations/sec.
        # DCM4109: 12 commutations per motor rev (4 poles x 3 phases) x 22.667
        # gearbox = 272 per WHEEL rev. So 60/272 makes both setTargetVelocity()
        # and getVelocity() speak wheel RPM, matching /wheel_rpm directly.
        #
        # VERIFY ONCE ON THE BENCH: command a known RPM, measure real wheel RPM
        # (phone slow-mo works). If you're off by exactly 272/60 or its
        # reciprocal, flip this. Phidget's multiply-vs-divide convention is the
        # one thing here worth confirming by hand rather than trusting.
        self.declare_parameter('rescale_factor', 60.0 / 272.0)

        # ── Motion limits / safety ───────────────────────────────────────────
        self.declare_parameter('current_limit', 10.0)       # A. DCC1120 floor is 5A.
        self.declare_parameter('acceleration', 500.0)       # wheel RPM/s ramp
        self.declare_parameter('max_wheel_rpm', 170.0)      # DCM4109 rated output
        self.declare_parameter('command_timeout_sec', 0.3)  # stale cmd -> stop

        # ── Odometry ─────────────────────────────────────────────────────────
        self.declare_parameter('publish_odom', True)
        self.declare_parameter('publish_tf', True)
        self.declare_parameter('odom_rate_hz', 50.0)
        # Defaults match robot_params.yaml's /** wildcard block (which
        # normally overrides these) — CAD-measured values from
        # guardian_description/urdf/dimensions.xacro.
        self.declare_parameter('wheel_radius', 0.0775)      # VEX Pro 6"
        self.declare_parameter('wheel_base_length', 0.313588)
        self.declare_parameter('wheel_base_width', 0.390755)
        self.declare_parameter('odom_frame', 'odom')
        self.declare_parameter('base_frame', 'base_link')

        p = self.get_parameter
        self._hub_serial = int(p('hub_serial').value)
        self._ports = list(p('wheel_hub_ports').value)
        self._channel = int(p('channel').value)
        self._attach_timeout = int(p('attach_timeout_ms').value)
        self._dirs = list(p('wheel_directions').value)
        self._rescale = float(p('rescale_factor').value)
        self._current_limit = float(p('current_limit').value)
        self._accel = float(p('acceleration').value)
        self._max_rpm = float(p('max_wheel_rpm').value)
        self._cmd_timeout = float(p('command_timeout_sec').value)

        self._publish_odom = bool(p('publish_odom').value)
        self._publish_tf = bool(p('publish_tf').value)
        self._r = float(p('wheel_radius').value)
        self._L = float(p('wheel_base_length').value) / 2.0
        self._W = float(p('wheel_base_width').value) / 2.0
        self._odom_frame = p('odom_frame').value
        self._base_frame = p('base_frame').value

        # ── Startup scan ─────────────────────────────────────────────────────
        # _reattach_logged tracks whether the "missing" state for a wheel has
        # already been logged, so the periodic retry timer below doesn't
        # spam an identical error every cycle while a wheel is genuinely
        # still disconnected — only real state changes (missing -> found,
        # found -> missing) get logged.
        self._reattach_logged = [False] * 4
        self._motors = [self._open_motor(i) for i in range(4)]

        live = [WHEEL_NAMES[i] for i in range(4) if self._motors[i] is not None]
        skipped = [WHEEL_NAMES[i] for i in range(4) if self._ports[i] < 0]
        missing = [WHEEL_NAMES[i] for i in range(4)
                   if self._ports[i] >= 0 and self._motors[i] is None]

        self.get_logger().info(f'Wheels driving: {live or "NONE"}')
        if skipped:
            self.get_logger().info(f'Wheels not wired yet (port -1): {skipped}')
        if missing:
            self.get_logger().error(
                f'Wheels CONFIGURED BUT NOT FOUND: {missing}. '
                'Check 24V power and VINT cabling for those ports.')
            for i in missing:
                self._reattach_logged[WHEEL_NAMES.index(i)] = True
        if not live:
            self.get_logger().error(
                'No controllers attached — node is up but will not move anything.')

        # ── Pose state ───────────────────────────────────────────────────────
        self._x = 0.0
        self._y = 0.0
        self._yaw = 0.0

        # ── ROS interface ────────────────────────────────────────────────────
        self._last_cmd_time = self.get_clock().now()
        self.create_subscription(
            Float32MultiArray, '/wheel_rpm', self._wheel_rpm_callback, 10)

        self._odom_pub = None
        self._tf_broadcaster = None
        if self._publish_odom:
            self._odom_pub = self.create_publisher(Odometry, '/odom', 10)
            if self._publish_tf:
                self._tf_broadcaster = TransformBroadcaster(self)
            self._last_odom_time = self.get_clock().now()
            self.create_timer(1.0 / float(p('odom_rate_hz').value), self._odom_timer)

        self.create_timer(0.05, self._watchdog)  # 20 Hz
        # Per-motor reattach retry — see _reattach_missing_motors for why
        # this exists instead of relying on respawn=True/an external
        # watchdog: only ONE of four independent channels typically fails
        # (a single loose VINT cable, or one channel losing its Phidget22
        # attachment mid-session), and killing/respawning the whole node
        # would needlessly also bounce the three wheels already working.
        self.create_timer(5.0, self._reattach_missing_motors)

        self.get_logger().info(
            f'phidget_bridge_node started (odom={self._publish_odom}, '
            f'tf={self._publish_tf})')

    # ── Setup ────────────────────────────────────────────────────────────────
    def _open_motor(self, index, quiet=False):
        name = WHEEL_NAMES[index]
        port = self._ports[index]
        if port is None or port < 0:
            return None  # deliberately not wired yet

        ch = MotorVelocityController()
        if self._hub_serial:
            ch.setDeviceSerialNumber(self._hub_serial)
        ch.setHubPort(int(port))
        ch.setChannel(self._channel)

        try:
            ch.openWaitForAttachment(self._attach_timeout)
        except PhidgetException as e:
            if not quiet:
                self.get_logger().error(
                    f'{name}: no controller on hub port {port} ({e.details})')
            return None

        try:
            # Confirmed live: a reattaching motor can be found already
            # spinning with nobody commanding it. The DCC1120 board itself
            # is powered continuously off the 24V rail via the VINT hub —
            # only its USB/VINT COMMUNICATION link drops on a detach, not
            # its power — so the board's own engaged/target state isn't
            # guaranteed to reset just because we lost and regained the
            # connection. Disengage FIRST, before touching anything else,
            # so the motor is guaranteed unable to actively drive for the
            # entire rest of setup; only zero the target and re-engage as
            # the last two steps, in that order, once everything else is
            # confirmed configured.
            ch.setEngaged(False)
            ch.setRescaleFactor(self._rescale)
            ch.setCurrentLimit(self._current_limit)
            ch.setAcceleration(self._accel)
            ch.setTargetVelocity(0.0)
            ch.setEngaged(True)  # REQUIRED — otherwise it freewheels
            # Phidget22's own disconnect event (base Phidget class, not
            # MotorVelocityController-specific) — catches a mid-session
            # physical disconnect (cable worked loose, USB/VINT bus glitch)
            # immediately, rather than only finding out the next time a
            # command happens to throw. Just clears the slot; the periodic
            # _reattach_missing_motors timer picks it back up from there,
            # same path as a wheel that was never found at startup.
            ch.setOnDetachHandler(
                lambda _ch, i=index, n=name: self._on_motor_detached(i, n))
        except PhidgetException as e:
            self.get_logger().error(f'{name}: config failed ({e.details})')
            try:
                ch.close()
            except PhidgetException:
                pass
            return None

        self.get_logger().info(f'{name}: ready on hub port {port}')
        return ch

    def _on_motor_detached(self, index, name):
        # Fires on Phidget22's own event thread, not the ROS executor —
        # kept to a single list assignment (atomic under the GIL) plus a
        # log call, nothing that touches hardware or needs a lock.
        self.get_logger().warn(f'{name}: detached — will retry attaching')
        self._motors[index] = None
        self._reattach_logged[index] = True  # already logged, don't repeat

    def _reattach_missing_motors(self):
        for i in range(4):
            if self._ports[i] < 0 or self._motors[i] is not None:
                continue  # not wired, or already attached — nothing to do
            motor = self._open_motor(i, quiet=self._reattach_logged[i])
            if motor is not None:
                self._motors[i] = motor
                self._reattach_logged[i] = False
                self.get_logger().info(f'{WHEEL_NAMES[i]}: reattached')
            else:
                self._reattach_logged[i] = True

    # ── Commands ─────────────────────────────────────────────────────────────
    def _wheel_rpm_callback(self, msg: Float32MultiArray):
        if len(msg.data) < 4:
            self.get_logger().warn('wheel_rpm: expected 4 values [FL,FR,BL,BR]')
            return
        self._last_cmd_time = self.get_clock().now()
        for i in range(4):
            self._set_wheel(i, float(msg.data[i]))

    def _set_wheel(self, index, rpm):
        motor = self._motors[index]
        if motor is None:
            return
        rpm = max(-self._max_rpm, min(self._max_rpm, rpm))
        try:
            motor.setTargetVelocity(self._dirs[index] * rpm)
        except PhidgetException as e:
            self.get_logger().error(
                f'{WHEEL_NAMES[index]}: setTargetVelocity failed ({e.details})')

    def _watchdog(self):
        age = (self.get_clock().now() - self._last_cmd_time).nanoseconds / 1e9
        if age > self._cmd_timeout:
            for i in range(4):
                self._set_wheel(i, 0.0)

    # ── Feedback ─────────────────────────────────────────────────────────────
    def _read_wheel_rad_s(self, index):
        """Measured wheel speed in rad/s, in the robot's sign convention.

        getVelocity() returns measured velocity; with rescale_factor set above
        that's wheel RPM. Undo the per-wheel direction flip so the kinematics
        sees consistent signs.

        A wheel that isn't wired reads 0.0, which would skew the mecanum
        averages, so odom is only meaningful with all four connected.
        """
        motor = self._motors[index]
        if motor is None:
            return 0.0
        try:
            rpm = motor.getVelocity()
        except PhidgetException:
            return 0.0
        rpm *= self._dirs[index]
        return rpm * 2.0 * math.pi / 60.0

    def _odom_timer(self):
        now = self.get_clock().now()
        dt = (now - self._last_odom_time).nanoseconds / 1e9
        if dt <= 0.0:
            return
        self._last_odom_time = now

        fl = self._read_wheel_rad_s(FL)
        fr = self._read_wheel_rad_s(FR)
        bl = self._read_wheel_rad_s(BL)
        br = self._read_wheel_rad_s(BR)

        # Mecanum forward kinematics — same form as the old serial bridge.
        r = self._r
        vx = r / 4.0 * (fl + fr + bl + br)
        vy = r / 4.0 * (-fl + fr + bl - br)
        omega = r / (4.0 * (self._L + self._W)) * (-fl + fr - bl + br)

        self._x += (vx * math.cos(self._yaw) - vy * math.sin(self._yaw)) * dt
        self._y += (vx * math.sin(self._yaw) + vy * math.cos(self._yaw)) * dt
        self._yaw += omega * dt

        self._publish(vx, vy, omega, now)

    def _publish(self, vx, vy, omega, stamp):
        qz = math.sin(self._yaw / 2.0)
        qw = math.cos(self._yaw / 2.0)

        odom = Odometry()
        odom.header.stamp = stamp.to_msg()
        odom.header.frame_id = self._odom_frame
        odom.child_frame_id = self._base_frame
        odom.pose.pose.position.x = self._x
        odom.pose.pose.position.y = self._y
        odom.pose.pose.orientation.z = qz
        odom.pose.pose.orientation.w = qw
        odom.twist.twist.linear.x = vx
        odom.twist.twist.linear.y = vy
        odom.twist.twist.angular.z = omega

        # Mecanum wheel odometry slips, and hall feedback is coarse (272 counts
        # per wheel rev). Keep covariance honest so the EKF weights this
        # sensibly instead of trusting it like a laser.
        odom.pose.covariance[0] = 0.05    # x
        odom.pose.covariance[7] = 0.05    # y
        odom.pose.covariance[35] = 0.10   # yaw
        odom.twist.covariance[0] = 0.05
        odom.twist.covariance[7] = 0.05
        odom.twist.covariance[35] = 0.10
        self._odom_pub.publish(odom)

        if self._tf_broadcaster is not None:
            tf = TransformStamped()
            tf.header.stamp = stamp.to_msg()
            tf.header.frame_id = self._odom_frame
            tf.child_frame_id = self._base_frame
            tf.transform.translation.x = self._x
            tf.transform.translation.y = self._y
            tf.transform.rotation.z = qz
            tf.transform.rotation.w = qw
            self._tf_broadcaster.sendTransform(tf)

    # ── Teardown ─────────────────────────────────────────────────────────────
    def shutdown(self):
        for motor in self._motors:
            if motor is None:
                continue
            try:
                motor.setTargetVelocity(0.0)
                motor.setEngaged(False)
                motor.close()
            except PhidgetException:
                pass


def main(args=None):
    rclpy.init(args=args)
    node = PhidgetBridgeNode()
    try:
        rclpy.spin(node)
    except KeyboardInterrupt:
        pass
    finally:
        node.shutdown()
        node.destroy_node()
        rclpy.shutdown()


if __name__ == '__main__':
    main()

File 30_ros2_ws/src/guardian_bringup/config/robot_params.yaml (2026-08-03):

# Shared hardware constants — ONE place to edit. Every node below inherits
# these via ROS2's wildcard parameter matching (`/**`), so a real-world
# change (new wheels, a different motor) only ever needs changing here.
#
# Do NOT redeclare wheel_radius/wheel_base_length/wheel_base_width/max_rpm/
# max_wheel_rpm inside any node-specific block below — a node-scoped entry
# always wins over a wildcard one, so a re-added copy would silently shadow
# this block and reintroduce the exact stale-duplicate-value bug already
# found and fixed here twice (mecanum_kinematics_node and serial_bridge_node
# were independently carrying two different sets of pre-CAD placeholder
# numbers before today).
/**:
  ros__parameters:
    # CAD-measured (guardian_description/urdf/dimensions.xacro) — VEX Pro 6" mecanum wheels.
    wheel_radius: 0.0775
    wheel_base_length: 0.313588
    wheel_base_width: 0.390755
    # DCM4109 rated max continuous speed. Two keys because
    # mecanum_kinematics_node and phidget_bridge_node were written
    # independently under different names for the same real-world fact —
    # kept both here rather than renaming either node's parameter, so this
    # is still the only place either one needs editing.
    max_rpm: 170.0
    max_wheel_rpm: 170.0

serial_bridge_node:
  ros__parameters:
    serial_port_left: /dev/ttyACM0
    serial_port_right: /dev/ttyACM1
    baud_rate: 115200
    serial_timeout: 1.0
    cpr: 272.0  # confirmed on the real robot: 4-pole hall sensors (12 ticks/motor-rev) x 22.667:1 gearbox
    max_ticks_per_sec: 3000.0  # declared but unused in serial_bridge_node.py — not wired to anything
    sim_mode: false

# wheel_radius/wheel_base_length/wheel_base_width all come from the /**
# wildcard above — mecanum_kinematics_node has no parameters of its own
# beyond those.
mecanum_kinematics_node:
  ros__parameters: {}

# Owner: Vedant. Talks to the DCC1120 controllers directly over VINT via the
# Phidget22 API — drop-in replacement for serial_bridge_node (same
# /wheel_rpm in, same /odom out). wheel_radius/wheel_base_length/
# wheel_base_width/max_wheel_rpm come from the /** wildcard above.
phidget_bridge_node:
  ros__parameters:

    # ── Addressing ─────────────────────────────────────────────────────────
    # Serial of the VINT HUB. All DCC1120s report this same number; the hub
    # port is what distinguishes them.
    hub_serial: 782265

    # VINT hub port per wheel, order [FL, FR, BL, BR].
    # -1 = not wired (that wheel is skipped, node still runs) — handy for
    # bringing wheels up one at a time.
    wheel_hub_ports: [0, 5, 1, 4]

    # Per-wheel sign so +RPM drives that corner forward.
    # Left and right motors are mirror-mounted, so they take opposite signs.
    # Confirm each one empirically before trusting strafing.
    wheel_directions: [1, -1, 1, -1]

    # ── Calibration ────────────────────────────────────────────────────────
    # 60/272: 12 commutations per motor rev x 22.667 gearbox = 272 per wheel
    # rev, so the controller speaks wheel RPM. Confirmed on the real robot.
    rescale_factor: 0.220588

    # ── Limits / safety ────────────────────────────────────────────────────
    current_limit: 10.0        # A (DCC1120 floor is 5A)
    acceleration: 200.0        # wheel RPM/s
    command_timeout_sec: 0.3   # no /wheel_rpm for this long -> stop

    # ── Odometry ───────────────────────────────────────────────────────────
    publish_odom: true
    publish_tf: true           # set false if something else owns odom->base_link
    odom_rate_hz: 50.0
    odom_frame: odom
    base_frame: base_link

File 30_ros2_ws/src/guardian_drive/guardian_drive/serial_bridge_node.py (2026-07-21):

# MIT License
# GUARDIAN — StarkHacks 2026
# Node: serial_bridge_node
# Purpose: sends RPM targets to two ESP32 boards over USB serial, optionally reads encoder feedback and publishes /odom
# Layout: LEFT ESP32 = FL+BL (M1=FL, M2=BL), RIGHT ESP32 = FR+BR (M1=FR, M2=BR)

import math
import serial
import rclpy
from rclpy.node import Node
from std_msgs.msg import Float32MultiArray
from nav_msgs.msg import Odometry
from geometry_msgs.msg import TransformStamped
from tf2_ros import TransformBroadcaster


class SerialBridgeNode(Node):
    def __init__(self):
        super().__init__('serial_bridge_node')

        self.declare_parameter('serial_port',       '')
        self.declare_parameter('serial_port_left',  '/dev/ttyACM0')
        self.declare_parameter('serial_port_right', '/dev/ttyACM1')
        self.declare_parameter('baud_rate',          115200)
        self.declare_parameter('serial_timeout',     1.0)
        # Defaults match robot_params.yaml (which normally overrides these) —
        # CAD-measured values from guardian_description/urdf/dimensions.xacro.
        self.declare_parameter('wheel_radius',       0.0775)
        self.declare_parameter('wheel_base_length',  0.313588)
        self.declare_parameter('wheel_base_width',   0.390755)
        # Confirmed on the real robot: 4-pole hall sensors (12 ticks per
        # motor-shaft rev) x 22.667:1 gearbox = 272 ticks/wheel-rev.
        self.declare_parameter('cpr',                272.0)
        self.declare_parameter('max_ticks_per_sec',  3000.0)
        self.declare_parameter('sim_mode',           False)
        self.declare_parameter('publish_odom',       True)
        self.declare_parameter('publish_tf',         True)

        self.sim_mode  = self.get_parameter('sim_mode').value
        self.publish_odom = self.get_parameter('publish_odom').value
        self.publish_tf = self.get_parameter('publish_tf').value
        serial_port    = self.get_parameter('serial_port').value
        port_left      = self.get_parameter('serial_port_left').value
        port_right     = self.get_parameter('serial_port_right').value
        baud           = self.get_parameter('baud_rate').value
        timeout        = self.get_parameter('serial_timeout').value
        self.cpr               = self.get_parameter('cpr').value
        self.max_ticks_per_sec = self.get_parameter('max_ticks_per_sec').value

        if self.sim_mode:
            self.serial_mode = 'sim'
            self.ser_single = self.ser_left = self.ser_right = None
            self.get_logger().warn('sim_mode=true — serial disabled, publishing zero odometry')
        elif serial_port:
            self.serial_mode = 'single_arduino'
            self.ser_single = self._open_port(serial_port, baud, timeout)
            self.ser_left = self.ser_right = None
        else:
            self.serial_mode = 'dual_esp32'
            self.ser_single = None
            self.ser_left  = self._open_port(port_left,  baud, timeout)
            self.ser_right = self._open_port(port_right, baud, timeout)

        self.sub = self.create_subscription(
            Float32MultiArray, '/wheel_rpm', self.rpm_callback, 10)
        self.odom_pub = None
        self.tf_broadcaster = None
        if self.publish_odom:
            self.odom_pub = self.create_publisher(Odometry, '/odom', 10)
            if self.publish_tf:
                self.tf_broadcaster = TransformBroadcaster(self)

        self.x = self.y = self.yaw = 0.0
        self.last_time = self.get_clock().now()

        # Cumulative tick tracking (per-board timestamps)
        # LEFT board:  M1=FL, M2=BL
        # RIGHT board: M1=FR, M2=BR
        self._prev_fl = self._prev_bl = 0
        self._prev_fr = self._prev_br = 0
        self._prev_tick_time_single = self.get_clock().now()
        self._prev_tick_time_left  = self.get_clock().now()
        self._prev_tick_time_right = self.get_clock().now()

        # Latest velocity estimates (ticks/sec)
        self._vel_fl = self._vel_fr = 0.0
        self._vel_bl = self._vel_br = 0.0

        if self.publish_odom:
            self.create_timer(0.02, self.read_encoders)  # 50 Hz

        if self.serial_mode == 'single_arduino':
            self.get_logger().info(
                f'serial_bridge_node started (MODE=single_arduino, PORT={serial_port}, '
                f'publish_odom={self.publish_odom}, publish_tf={self.publish_tf})')
        else:
            self.get_logger().info(
                f'serial_bridge_node started (MODE={self.serial_mode}, LEFT={port_left}, '
                f'RIGHT={port_right}, publish_odom={self.publish_odom}, '
                f'publish_tf={self.publish_tf})')

    def _open_port(self, port, baud, timeout):
        try:
            s = serial.Serial(port, baud, timeout=timeout)
            self.get_logger().info(f'Opened {port} at {baud} baud')
            return s
        except serial.SerialException as e:
            self.get_logger().warn(f'Could not open {port}: {e}')
            return None

    # ── Commands ────────────────────────────────────────────────────────────────
    def rpm_callback(self, msg: Float32MultiArray):
        if len(msg.data) < 4:
            self.get_logger().warn('wheel_rpm: need 4 values')
            return
        fl_rpm, fr_rpm, bl_rpm, br_rpm = msg.data[:4]

        if self.serial_mode == 'single_arduino':
            self._write_safe(
                self.ser_single,
                f'FL:{int(round(fl_rpm))} FR:{int(round(fr_rpm))} '
                f'BL:{int(round(bl_rpm))} BR:{int(round(br_rpm))}\n',
                'MAIN')
            return

        # LEFT board drives FL (M1) and BL (M2)
        self._write_safe(self.ser_left,  f'M1:{fl_rpm:.2f} M2:{bl_rpm:.2f}\n', 'LEFT')
        # RIGHT board drives FR (M1) and BR (M2)
        self._write_safe(self.ser_right, f'M1:{fr_rpm:.2f} M2:{br_rpm:.2f}\n', 'RIGHT')

    def _write_safe(self, ser, line, label):
        if ser is None:
            return
        try:
            ser.write(line.encode())
        except (serial.SerialException, OSError) as e:
            self.get_logger().error(f'Serial write ({label}): {e}')

    # ── Encoder reading ──────────────────────────────────────────────────────────
    def read_encoders(self):
        if not self.publish_odom:
            return
        if self.sim_mode or (self.ser_single is None and self.ser_left is None and self.ser_right is None):
            self._publish_odom(0.0, 0.0, 0.0, self.get_clock().now())
            return

        if self.serial_mode == 'single_arduino':
            updated = self._read_single_board(self.ser_single, 'MAIN')
        else:
            updated = False
            updated |= self._read_board(self.ser_left,  'LEFT',  is_left=True)
            updated |= self._read_board(self.ser_right, 'RIGHT', is_left=False)
        if updated:
            self._compute_odom()
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

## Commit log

2026-07-19 Kienmatics Updatae in Simand Keyboard teleop
    [guardian_sim.urdf.xacro, robot_params.yaml]
2026-07-19 Added enumerate script, updated spin test, and tweaked robot params
    [robot_params.yaml]
2026-07-21 cad to ursf skript plus impelmtsaion in sim
    [dimensions.xacro, guardian_sim.urdf.xacro, lidar.stl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]
2026-07-21 Add lidar merger node and configuration for LIDAR self-occlusion masking
2026-07-21 Update CPR parameter in serial_bridge_node and robot_params.yaml to match real robot specifications
    [robot_params.yaml]
2026-07-21 Update LIDAR configuration and add identification scripts for stable device naming
2026-07-21 Update wheel parameters in phidget_bridge_node for improved robot specifications
2026-07-21 Refactor robot description and launch configurations BIG CLEANUP
    [guardian.urdf.xacro, guardian_sim.urdf.xacro]
2026-07-21 Refactor RViz configurations and remove RealSense camera dependencies for improved compatibility
2026-07-30 Fix strafe direction in mecanum kinematics by negating vy for accurate wheel RPM calculations
    [mecanum_kinematics_node.py]
2026-07-30 Add pause + center-pedal to collection; archive retired infer scripts; add udev identify script
    - collect.py: spacebar/pedal pause between episodes, auto-pause every N, progress hints
    - pedal_bridge.py: center pedal -> spacebar (pause)
    - move infer.py/infer_eval.py/bimanual_inference.py to archive/ (superseded by lerobot-rollout)
    - identify_arm_cam_ports.sh: interactive udev rule generator for arms + cameras
    - 99-guardian.rules: regenerated
2026-08-01 Refactor GUARDIAN launch files and hardware management
    - Consolidated launch files: Removed individual launch files for sim/real and combined functionalities into `guardian.launch.py` and a new `guardian_hardware.launch.py`.
    - Updated README.md to reflect changes in launch file usage and hardware management.
    - Modified `robot_params.yaml` to adjust wheel hub ports for better hardware configuration.
    - Enhanced `activate_lifecycle_node.sh` to handle shutdown signals properly, preventing orphan processes.
    - Improved `phidget_bridge_node.py` to manage motor reattachment and logging for disconnected motors.
    - Added a new `hardware_watchdog.sh` script to monitor hardware nodes for data flow and re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
    [robot_params.yaml]
2026-08-03 feat: add simulation and web control interface for GUARDIAN
    - Introduced guardian_sim.launch.py for a dedicated simulation environment, allowing continuous operation across mode switches without resetting Gazebo.
    - Implemented nav_status_node.py to provide read-only status signals for the browser control interface, including navigation status and stack readiness.
    - Created web_ops_node.py to expose custom actions for mode switching and map saving via the browser interface.
    - Added scripts for running the simulation and web control interface, ensuring proper background management of processes.
    - Set up systemd services for hardware, foxglove_bridge, and web_ops_node to facilitate automatic st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
2026-08-03 Update device rules and configuration parameters for improved functionality; adjust home position, episode settings, and reset behavior.
    [server_stage2.py]
2026-08-04 Refactor servo attachment parameters and update calibration procedure in main.cpp; add calibration sketch for precise home pulse widths

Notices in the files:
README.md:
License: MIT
